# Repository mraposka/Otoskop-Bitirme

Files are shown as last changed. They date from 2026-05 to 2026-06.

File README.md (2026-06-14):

# Otoskop — Motorlu Akıllı Teleskop / Gökyüzü İşaretleyici

Otoskop; bir gök cismini (gezegen, yıldız, takımyıldız vb.) seçtiğinde, kendi
konumunu ve yönelimini ölçüp teleskopu **otomatik olarak** o hedefin azimut/
yükseklik (altitude) açısına döndüren, üzerindeki kamera ile canlı görüntü
veren bir bitirme projesidir.

Sistem üç parçadan oluşur:

1. **Arduino Mega 2560** — "kas + duyu": IMU/pusula, GPS ve iki servo motoru
   sürer. Hedefe yumuşak şekilde nişan alır.
2. **ESP32-CAM (AI-Thinker)** — "ağ geçidi + göz": Wi-Fi, HTTP API, kamera
   (anlık kare + canlı MJPEG yayını) ve Mega ile köprü görevi görür.
3. **Android uygulaması** — kullanıcı arayüzü: hedef seçimi, manuel oynatma,
   kalibrasyon, canlı kamera, telemetri gösterimi.

```
   ┌──────────────┐   Wi-Fi/HTTP   ┌──────────────┐   UART (JSON)  ┌──────────────┐
   │ Android App  │ ─────────────► │  ESP32-CAM   │ ─────────────► │ Arduino Mega │
   │ (hedef/UI)   │ ◄───────────── │ (ağ + kamera)│ ◄───────────── │ (sensör+motor)│
   └──────────────┘   status/JPEG  └──────────────┘   telemetri    └──────────────┘
                                                                         │
                                                            ┌────────────┼────────────┐
                                                         MPU9250        GPS        2x Servo
                                                       (IMU+pusula)  (NEO-6M)    (azimut/alt)
```

---

## İçindekiler

- [Depo yapısı](#depo-yapısı)
- [Nasıl çalışır?](#nasıl-çalışır)
- [Donanım ve kablolama](#donanım-ve-kablolama)
- [Yazılım kurulumu (Arduino IDE)](#yazılım-kurulumu-arduino-ide)
- [Mega firmware yükleme](#mega-firmware-yükleme)
- [ESP32-CAM firmware yükleme](#esp32-cam-firmware-yükleme)
- [Wi-Fi ve cihaz bulma](#wi-fi-ve-cihaz-bulma)
- [HTTP API](#http-api)
- [UART köprüsü ve JSON protokolü](#uart-köprüsü-ve-json-protokolü)
- [Kablosuz kod yükleme (OTA)](#kablosuz-kod-yükleme-ota)
- [Sorun giderme](#sorun-giderme)

---

## Depo yapısı

```
Otoskop/
├── ESP32_Arduino_Firmware/
│   └── mega_otoskop/
│       └── mega_otoskop.ino        # Arduino Mega 2560 firmware (sensör + motor)
├── ESP32_Pure_Firmware/
│   ├── esp32cam_otoskop/
│   │   └── esp32cam_otoskop.ino    # ESP32-CAM firmware (Wi-Fi + kamera + köprü)
│   └── ota/
│       ├── firmware.bin            # Bulut OTA için yayınlanan derlenmiş binary
│       └── version.json            # OTA sürüm bilgisi {"version", "url"}
├── ota_release/
│   └── release.ps1                 # OTA yayın yardımcısı (PowerShell)
├── ServoTest.ino                   # Servo açı testi için bağımsız yardımcı sketch
└── README.md
```

> Not: `firmware.bin` bilerek repoda tutulur (`.gitignore` onu istisna tutar),
> çünkü cihazlar OTA güncellemesini doğrudan GitHub raw URL'sinden indirir.

---

## Nasıl çalışır?

1. **Konum & yönelim ölçümü (Mega):**
   - GPS'ten enlem/boylam (lat/lon) alınır.
   - MPU9250 ile **azimut** (tilt-kompanze manyetometre + gyro complementary
     filter ile gerçek pusula yönü) ve **yükseklik açısı** (ivmeölçer pitch)
     hesaplanır.
2. **Hedef belirleme (App → ESP → Mega):**
   - Uygulama bir hedefin azimut/altitude değerini gönderir.
   - Mega, hedefi servo açısına haritalar ve motorları yumuşakça (slew) döndürür.
   - Hedefe yeterince yaklaşınca **kilit (lock)** durumu raporlanır.
3. **Geri bildirim (Mega → ESP → App):**
   - Mega ~10 Hz telemetri (anlık açı, hedef açı, servo açıları, GPS, IMU/track/
     lock durumları) yollar.
   - ESP bunu önbelleğe alır ve `/status` ile uygulamaya servis eder.
4. **Görüntü (ESP):**
   - Kamera tek kare (`/camera`) veya canlı MJPEG yayını (`/stream`, ayrı port)
     olarak verilir.

---

## Donanım ve kablolama

### Bileşenler

| Parça | Açıklama |
|---|---|
| Arduino Mega 2560 | Ana kontrolcü (sensör + motor) |
| ESP32-CAM (AI-Thinker) | Wi-Fi + kamera + köprü |
| MPU9250 | 9 eksenli IMU (ivme + gyro + AK8963 manyetometre) |
| GPS modülü | NEO-6M / M8N (TinyGPSPlus uyumlu) |
| 2x Servo | Azimut (pan) + Altitude (tilt) ekseni |
| USB–TTL adaptör | ESP32-CAM ilk programlaması için (kartta USB yoksa) |
| Gerilim bölücü | Mega 5V TX → ESP 3.3V RX hattı için |

### Mega bağlantıları

| Bağlantı | Pinler |
|---|---|
| MPU9250 | VCC 3.3V, GND, SDA → 20, SCL → 21 |
| GPS | VCC 5V, GND, GPS-TX → Mega RX2 (17), GPS-RX → Mega TX2 (16) |
| Servo Azimut | Sinyal → pin **9** (harici 5V besleme, ortak GND) |
| Servo Altitude | Sinyal → pin **10** |
| ESP link (TX) | Mega TX1 (18) → **gerilim bölücü 5V→3.3V** → ESP RX2 (GPIO13) |
| ESP link (RX) | Mega RX1 (19) ← ESP TX2 (GPIO15) (3.3V doğrudan) |

### ESP32-CAM bağlantıları

| Bağlantı | Pin |
|---|-----|
| Mega'dan veri girişi (RX2) | GPIO13 (Mega TX1 → gerilim bölücü üzerinden) |
| Mega'ya veri çıkışı (TX2) | GPIO15 (→ Mega RX1) |
| Flash LED (OTA göstergesi) | GPIO4 |

> ⚠️ **Kritik:** Her iki kartın **GND'si ortak** olmalıdır. Mega'nın 5V TX'i
> doğrudan ESP'ye bağlanmamalı; **gerilim bölücü** ile 3.3V'a düşürülmelidir.
> ESP'yi programlarken Mega bağlantısını sökün (UART karışmasın).

---

## Yazılım kurulumu (Arduino IDE)

### 1) ESP32 kart desteği

1. Arduino IDE → **File → Preferences → Additional boards manager URLs**
2. Şu adresi ekleyin:
   `https://espressif.github.io/arduino-esp32/package_esp32_index.json`
3. **Tools → Board → Boards Manager** → **esp32** (Espressif) yükleyin.

### 2) Kütüphaneler

**Sketch → Include Library → Manage Libraries** üzerinden kurun:

| Kütüphane | Yazar / Sürüm | Kullanan |
|---|---|---|
| **ArduinoJson** | Benoît Blanchon (6.x/7.x) | Mega + ESP |
| **TinyGPSPlus** | Mikal Hart | Mega |
| **Servo** | Arduino (built-in) | Mega |
| **ESP32Servo** | (alternatif, gerekirse) | — |

`WiFi`, `WebServer`, `Wire`, `esp_camera`, `ArduinoOTA`, `HTTPClient`,
`HTTPUpdate`, `ESPmDNS` ESP32 çekirdeğiyle birlikte gelir.

---

## Mega firmware yükleme

1. **File → Open** ile `ESP32_Arduino_Firmware/mega_otoskop/mega_otoskop.ino`
   dosyasını açın.
2. **Tools → Board → Arduino Mega or Mega 2560** seçin, doğru COM portunu seçin.
3. **Upload**.
4. Serial Monitor'ü **115200** baud'da açın.

`DEBUG_USB` sabiti `1` iken Mega, hem komutları (`[CMD] ...`), hem 10 Hz
telemetriyi (`{"az":...}`), hem de bir "kalp atışı" satırını (`[LOOP] n=... imuOk=...`)
USB seri monitöre yazar. Bu, sensör/bağlantı doğrulaması için çok kullanışlıdır.

### Mega'da ayarlanabilir parametreler

| Sabit | Açıklama |
|---|---|
| `AZ_RANGE_MIN_DEG` / `AZ_RANGE_MAX_DEG` | Azimut servosunun kapsadığı açı aralığı (varsayılan 0–180°) |
| `ALT_RANGE_MIN_DEG` / `ALT_RANGE_MAX_DEG` | Altitude servo aralığı (0–90°) |
| `SERVO_SLEW_DEG_PER_LOOP` | Servo yumuşatma hızı |
| `LOCK_TOLERANCE_DEG` | Hedef kilidi toleransı |
| `MAG_DECLINATION_DEG` | Yerel manyetik sapma (İstanbul ≈ +6°) |
| `magOffX/Y/Z` | Manyetometre hard-iron offset (kalibrasyonla bulunur) |

---

## ESP32-CAM firmware yükleme

1. **File → Open** ile
   `ESP32_Pure_Firmware/esp32cam_otoskop/esp32cam_otoskop.ino` açın.
2. **Tools** ayarları:

| Ayar | Değer |
|---|---|
| Board | **AI Thinker ESP32-CAM** |
| Upload Speed | 115200 veya 921600 |
| Flash Frequency | 80MHz |
| Partition Scheme | **Minimal SPIFFS (1.9MB APP with OTA)** (OTA için şart) |
| PSRAM | **Enabled** |

3. Kartta USB yoksa **USB–TTL** adaptör kullanın (GPIO0 ↔ GND ile boot moduna alıp
   reset). Doğru COM portunu seçip **Upload** edin.
4. Serial Monitor: **115200** baud.

İlk yükleme bir kez kabloyla yapılmalıdır; sonrasında OTA ile kablosuz
güncellenebilir.

---

## Wi-Fi ve cihaz bulma

ESP, **AP + STA** modunda aynı anda çalışır:

- **AP (erişim noktası):** SSID `Otoskop`, şifre `otoskop123`, IP genelde
  **192.168.4.1**. Android uygulaması doğrudan buna bağlanabilir.
- **STA (istemci):** `WIFI_NETS` listesindeki ağlardan (telefon hotspot'u / ev
  Wi-Fi'si) hangisi varsa ona bağlanır (`WiFiMulti`). Bu, internet erişimi ve
  bulut OTA için gerekir.
- **mDNS:** Cihaz kendini `otoskop.local` olarak yayınlar. Uygulama IP yerine bu
  adı kullanarak cihazı DHCP IP değişse bile otomatik bulabilir.

Ayarlar `esp32cam_otoskop.ino` dosyasında:

```cpp
const char* AP_SSID = "Otoskop";
const char* AP_PASS = "otoskop123";
WifiCred WIFI_NETS[] = {
  { "Nothing", "123456789a" },   // kendi ağ(lar)ını ekle
};
```

---

## HTTP API

API port **80**'de, MJPEG yayını ise tıkanmayı önlemek için ayrı bir port
**81**'de servis edilir.

| Metot | Endpoint | Açıklama |
|---|---|---|
| GET | `/status` | Telemetri JSON (uygulama bunu sürekli sorgular) |
| GET | `/camera` | Tek JPEG kare (snapshot) |
| GET | `/stream` | Canlı MJPEG yayını (**port 81**) |
| GET | `/gps` | `{"lat":.., "lon":.., "fix":bool}` |
| POST | `/target` | `{"name":.., "azimuth":.., "altitude":..}` |
| POST | `/move` | `{"direction":"left\|right\|up\|down", "step":"small\|medium\|large"}` |
| POST | `/correction` | `{"azimuthCorrection":.., "altitudeCorrection":..}` |
| POST | `/calibrate` | Gyro + manyetometre kalibrasyonunu tetikler |
| GET | `/ota/check` | Bulut OTA'yı hemen kontrol eder (yeni sürüm varsa günceller) |

Tüm yanıtlar CORS (`Access-Control-Allow-Origin: *`) başlığı taşır.

### `/status` yanıt alanları

```json
{
  "azimuth": 134.8, "altitude": 42.1,
  "targetAzimuth": 135.4, "targetAltitude": 42.8,
  "servoAz": 67.4, "servoAlt": 42.1,
  "gpsFix": true, "imuOk": true,
  "tracking": true, "targetLocked": false,
  "megaRaw": "...", "megaAgeMs": 80, "megaLines": 1234, "megaBytes": 56789
}
```

`megaRaw / megaAgeMs / megaLines / megaBytes` alanları Mega↔ESP UART bağlantısının
teşhisi içindir (uygulamadaki konsolda görünür). `megaBytes = 0` → fiziksel hat
yok (GND/gerilim bölücü/kablo); `megaAgeMs = -1` → Mega'dan hiç veri gelmedi.

---

## UART köprüsü ve JSON protokolü

ESP ile Mega, 115200 8N1 baud'da satır-sonlu (`\n`) JSON ile konuşur.

**ESP → Mega (komutlar):**

```json
{"cmd":"target","az":135.4,"alt":42.8}
{"cmd":"move","dir":"right","step":"medium"}
{"cmd":"correction","daz":-0.8,"dalt":0.5}
{"cmd":"track","on":true}
{"cmd":"calibrate"}
```

**Mega → ESP (telemetri, ~10 Hz):**

```json
{"az":134.8,"alt":42.1,"taz":135.4,"talt":42.8,"sAz":67.4,"sAlt":42.1,
 "roll":1.2,"pitch":42.1,"yaw":134.8,
 "gps":true,"lat":41.0,"lon":28.9,"imu":true,"trk":true,"lock":false}
```

---

## Kablosuz kod yükleme (OTA)

ESP firmware'i ilk kabloyla yüklendikten sonra **iki yolla** kablosuz
güncellenebilir:

### 1) Aynı ağda — ArduinoOTA

Bilgisayar ESP ile aynı ağdayken Arduino IDE → **Tools → Port** içinde
`otoskop at <IP>` belirir. Normal şekilde **Upload** yapılır.
OTA şifresi: `otoskop123`.

### 2) İnternet üzerinden — Bulut OTA (HTTP pull)

Masaüstü ile ESP farklı ağlardayken kullanılır. ESP belirli aralıklarla
(varsayılan **5 dk**) `version.json` dosyasını kontrol eder:

```json
{ "version": 12, "url": "https://.../firmware.bin" }
```

`version > FW_VERSION` ise `firmware.bin` indirilip cihaz kendini günceller
(indirme sırasında flash LED yanıp söner). `GET /ota/check` ile güncelleme
beklemeden tetiklenebilir.

### Yeni sürüm yayınlama

1. `esp32cam_otoskop.ino` içindeki `#define FW_VERSION` değerini artırın.
2. Arduino IDE → **Sketch → Export Compiled Binary**.
3. Proje kökünde PowerShell ile yardımcı betiği çalıştırın:

```powershell
./ota_release/release.ps1
```

Betik, derlenen `.bin`'i `ESP32_Pure_Firmware/ota/firmware.bin`'e kopyalar ve
`version.json`'daki sürümü `.ino`'daki `FW_VERSION` ile eşitler (BOM'suz UTF-8).
Ardından bu iki dosyayı GitHub'a yükleyin. ESP en geç 5 dk içinde kendini
günceller.

> ⚠️ Betik güvenlik kontrolü yapar: `.ino` dosyası `.bin`'den yeniyse uyarır —
> aksi halde cihaz sonsuz OTA döngüsüne girebilir. `FW_VERSION`'ı değiştirdikten
> sonra **mutlaka yeniden derleyin**.

---

## Sorun giderme

| Belirti | Olası neden / çözüm |
|---|---|
| Uygulamada "ESP32 bağlantısı sağlanamadı" | Telefon `Otoskop` AP'sine bağlı mı? IP `192.168.4.1` mi? mDNS için `otoskop.local` deneyin |
| `megaBytes = 0` | UART fiziksel hattı yok: ortak GND yok, gerilim bölücü yanlış, Mega TX1 (pin 18) / ESP RX2 (GPIO13) bağlantısı hatalı |
| `megaBytes` artıyor ama `megaLines = 0` | Sinyal var ama bozuk — her iki taraf da 115200 8N1 olmalı |
| `imuOk = false` (sürekli kırmızı) | MPU9250 I2C bağlantısı; kod 100 kHz'de çalışır ve saniyede bir yeniden init dener. Kabloları/SDA-SCL'yi kontrol edin |
| Kamera init hatası (`0x105`) | Besleme yetersiz/brownout; kod brownout dedektörünü kapatır, PWDN toggle + 20/10 MHz XCLK dener. Yeterli akım veren USB/güç kullanın |
| Pusula sapması | `calibrate` çalıştırın; `MAG_DECLINATION_DEG`'i kendi konumunuza göre ayarlayın |
| Stream açıkken API donuyor | Yeni firmware'de yayın ayrı portta (81); stream döngüsü içinde API pompalanır. Eski firmware'i güncelleyin |
| Bulut OTA sonsuz döngü | `FW_VERSION` artırıldı ama yeniden derlenmedi; `release.ps1` bu durumda uyarır |
| OTA: **Could Not Activate The Firmware** | İndirme tamam ama doğrulama/aktivasyon başarısız. **En sık neden:** cihaz veya `firmware.bin` **farklı Partition Scheme** ile derlenmiş (ör. cihazda *Huge APP No OTA*, OTA bin *Minimal SPIFFS*). **Çözüm:** Arduino IDE → AI Thinker ESP32-CAM → **Minimal SPIFFS (1.9MB APP with OTA)** + PSRAM Enabled ile **USB'den bir kez** yükle; GitHub'a koyacağın `.bin`'i de **aynı ayarlarla** Export Compiled Binary ile üret |

---

## Lisans / Notlar

Bu, eğitim amaçlı bir bitirme projesidir. Wi-Fi şifreleri, OTA şifresi ve
TLS ayarları (sertifika doğrulaması kapalı) hobi kullanımı içindir; üretim
ortamı için sertleştirilmelidir.

Tanıtım: [Video](https://www.youtube.com/watch?v=3B4UuJV4B6s)

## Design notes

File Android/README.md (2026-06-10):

# Otoskop — ESP32 Tabanlı Otonom Teleskop Mobil Uygulaması

Android Studio projesi (Kotlin, AGP 9.0.0). MVVM + Navigation + Retrofit/OkHttp +
Coroutines mimarisinde modüler yazılmıştır.

## Mimari

```
app/src/main/java/com/kou/otoskop/
├── OtoskopApp.kt                    # Application + servis locator
├── MainActivity.kt                  # Navigation host + runtime izin
├── core/
│   ├── AppConfig.kt                 # IP, port, timeout, polling sabitleri
│   ├── AppError.kt                  # Hata türleri (UI mesajına map'lenir)
│   ├── Resource.kt                  # Success / Failure sealed class
│   └── AstroMath.kt                 # azimuth wrap-around, yön etiketleri
├── data/
│   ├── model/                       # JSON DTO'ları (Moshi)
│   │   ├── TelescopeStatus.kt
│   │   ├── CelestialObject.kt
│   │   ├── VerifyResult.kt
│   │   ├── SkyArea.kt
│   │   └── PhoneSensorData.kt
│   ├── network/                     # Retrofit API'ları + factory
│   │   ├── Esp32Api.kt
│   │   ├── BackendApi.kt
│   │   ├── NetworkFactory.kt
│   │   └── EndpointRewriteInterceptor.kt
│   └── repository/
│       ├── Esp32Repository.kt       # status/move/target/correction/calibrate
│       ├── BackendRepository.kt     # observable-objects + verify-image
│       └── SensorRepository.kt      # FusedLocation + rotation vector
└── ui/
    ├── shared/                      # 4 ViewModel (paylaşılan)
    │   ├── ConnectionViewModel.kt
    │   ├── SensorViewModel.kt
    │   ├── TelescopeViewModel.kt
    │   └── ObjectsViewModel.kt
    ├── widget/                      # Custom view'lar
    │   ├── CompassView.kt           # döner kompas (Canvas)
    │   ├── MjpegView.kt             # MJPEG byte-stream parser
    │   ├── StatusChipView.kt
    │   └── AppErrorView.kt
    ├── connection/ConnectionFragment.kt
    ├── livecamera/LiveCameraFragment.kt
    ├── skyarea/SkyAreaFragment.kt
    ├── objectlist/
    │   ├── ObjectListFragment.kt
    │   └── CelestialObjectAdapter.kt
    └── control/TelescopeControlFragment.kt
```

### Tasarım kararları

- **Servis Locator**: `OtoskopApp` üzerinden tek `Esp32Repository`,
  `BackendRepository`, `SensorRepository` instance'ı; Hilt/Koin yerine
  manuel DI bu boyut için yeterli ve test edilebilir.
- **Endpoint rewrite interceptor**: kullanıcı bağlantı ekranında IP
  değiştirdiğinde Retrofit'i yeniden inşa etmiyoruz — OkHttp interceptor
  her isteğin host/port'unu rewrite ediyor.
- **`Resource<T>`**: `try/catch` her yerde dağılmasın diye Repository'ler
  `Resource.Success` veya `Resource.Failure(AppError)` döner.
- **Native MJPEG parser**: 3. parti widget yok; `MjpegView` JPEG SOI/EOI
  marker'larına göre frame çıkarır.
- **`activityViewModels()`**: 5 fragment arasında `TelescopeViewModel`,
  `ObjectsViewModel`, `SensorViewModel`, `ConnectionViewModel` paylaşılır.

## Gradle / Bağımlılıklar

Tek dokunuş gereksinimi (Android Studio "Sync Now"): değişiklikler
`gradle/libs.versions.toml`, `build.gradle.kts`, `app/build.gradle.kts`'da.

Eklenenler:

- Kotlin 2.0.21 plugin
- Coroutines (`org.jetbrains.kotlinx:kotlinx-coroutines-android`)
- Lifecycle / Fragment / Activity / Navigation (`androidx.navigation:*`)
- RecyclerView
- Retrofit + Moshi converter, OkHttp + logging-interceptor
- Play Services Location (FusedLocation)
- MockWebServer + coroutines-test (test bağımlılıkları)

## Gömülü taraf (Arduino Mega + ESP32-CAM)

Firmware proje kökündeki **[`../firmware/`](../firmware/README.md)** klasöründedir:

- **`firmware/mega_otoskop/`** (Arduino Mega 2560): MPU9250 (tilt-kompanze pusula +
  ivmeden yükseklik), GPS (TinyGPSPlus), 2 servo, complementary filter.
- **`firmware/esp32cam_otoskop/`** (AI-Thinker ESP32-CAM): Wi-Fi AP, HTTP API
  (`/status`, `/target`, `/move`, `/correction`, `/calibrate`, `/camera`, `/stream`,
  `/gps`), kamera ve Mega ile **UART JSON köprüsü**.

Akış: `Android ──WiFi/HTTP──► ESP32-CAM ──UART(JSON)──► Arduino Mega`. App yalnız
ESP ile konuşur; ESP, Mega'nın telemetrisini `/status` olarak servis eder. Kablolama
ve haberleşme protokolü için `firmware/README.md`.

## Gök cismi listesi + AI doğrulama (backend'siz)

Bu sürümde ayrı bir backend sunucu **yoktur**; app üçüncü-parti servisleri doğrudan kullanır:

- **Gözlemlenebilir objeler** → [Visible Planets API](https://api.visibleplanets.dev)
  (ücretsiz, anahtar gerekmez). Gezegenler + Ay + Güneş; az/alt penceresine göre
  cihazda filtrelenir.
- **Görüntü doğrulama** → Google **Gemini** (`gemini-2.5-flash-lite`), app'ten direkt
  multimodal çağrı. Anahtar **Bağlantı ekranında** girilir (cihazda saklanır).
- İlgili kod: `data/network/AstroApi.kt`, `data/network/GeminiApi.kt`,
  `data/repository/DirectBackendRepository.kt`.

## Çalıştırma

1. Android Studio'da projeyi aç → Gradle Sync.
2. Telefonu USB ile bağla veya emülatör başlat.
3. Run.
4. İlk açılışta konum izni ister; sensörler ve GPS otomatik başlar.

## Testler

```bash
gradlew test
```

Test dosyaları:

- `core/AstroMathTest.kt` — azimuth wrap-around mantığı.
- `data/Esp32RepositoryTest.kt` — MockWebServer ile status / target / move.
- `data/BackendRepositoryTest.kt` — observable-objects query parametreleri
  ve `verify-image` cevap akışları (success + correction + not-verified).

## Hata yönetimi

`AppErrorKind` enum'undan UI'a banner:

| Kind | Mesaj |
|---|---|
| `ESP32_UNREACHABLE` | ESP32 bağlı değil |
| `CAMERA_STREAM_FAILED`  | Kamera stream alınamıyor |
| `GPS_UNAVAILABLE` | GPS konumu yok |
| `COMPASS_UNCALIBRATED`  | Telefon pusulası kalibre değil |
| `BACKEND_UNREACHABLE` | Backend API cevap vermiyor |
| `TARGET_NOT_VERIFIED` | Hedef doğrulanamadı |
| `PERMISSION_DENIED` | Gerekli izinler verilmedi |

---

## Uçtan Uca Akış & Örnek İstekler

### 1) ESP32 status polling

`TelescopeViewModel.startPolling()` 750ms'de bir:

```http
GET /status HTTP/1.1
Host: 192.168.4.1
```

Cevap:

```json
{
  "azimuth": 134.8, "altitude": 42.1,
  "targetAzimuth": 135.4, "targetAltitude": 42.8,
  "servoAz": 67.4, "servoAlt": 42.1,
  "gpsFix": true, "imuOk": true,
  "tracking": true, "targetLocked": false
}
```

### 2) Sky Area seçimi → backend obje listesi

```http
GET /observable-objects?latitude=41.0151&longitude=28.9795
    &datetime=2026-05-14T20:30:00Z
    &azimuthMin=120.0&azimuthMax=150.0
    &altitudeMin=30.0&altitudeMax=60.0 HTTP/1.1
Host: backend.example.com
```

Cevap:

```json
[
  { "name": "Mars", "type": "planet", "azimuth": 135.4, "altitude": 42.8,
    "magnitude": -1.2, "visible": true },
  { "name": "Arcturus", "type": "star", "azimuth": 128.0, "altitude": 51.2,
    "magnitude": 0.0, "visible": true }
]
```

### 3) Kullanıcı Mars'ı seçer → ESP32'ye target gönder

```http
POST /target HTTP/1.1
Host: 192.168.4.1
Content-Type: application/json

{ "name": "Mars", "azimuth": 135.4, "altitude": 42.8 }
```

### 4) Snapshot al → backend'e gönder (multipart)

```http
POST /verify-image HTTP/1.1
Host: backend.example.com
Content-Type: multipart/form-data; boundary=...

targetName=Mars
latitude=41.0151
longitude=28.9795
azimuth=134.8
altitude=42.1
image=<JPEG bytes>
```

Düzeltme gerekirse:

```json
{
  "verified": false, "targetName": "Mars",
  "azimuthCorrection": -0.8, "altitudeCorrection": 0.5,
  "message": "Move slightly left and up"
}
```

Doğrulandıysa:

```json
{
  "verified": true, "targetName": "Mars",
  "azimuthCorrection": 0, "altitudeCorrection": 0,
  "message": "Target verified"
}
```

### 5) App otomatik düzeltme gönderir

```http
POST /correction HTTP/1.1
Host: 192.168.4.1
Content-Type: application/json

{ "azimuthCorrection": -0.8, "altitudeCorrection": 0.5 }
```

### 6) Manuel hareket (kullanıcı "sağ + orta")

```http
POST /move HTTP/1.1
Host: 192.168.4.1
Content-Type: application/json

{ "direction": "right", "step": "medium" }
```

`direction`: `left | right | up | down`
`step`: `small | medium | large`

### 7) Kalibrasyon

```http
POST /calibrate HTTP/1.1
Host: 192.168.4.1
```

### 8) MJPEG canlı stream

`MjpegView`, ESP32'nin `multipart/x-mixed-replace` cevabını okur ve her
JPEG frame'ini ImageView'e bağlar:

```http
GET /stream HTTP/1.1
Host: 192.168.4.1
```

---

## Notlar

- `AndroidManifest.xml` `usesCleartextTraffic="true"` + ESP32 IP'leri
  `res/xml/network_security_config.xml`'de whitelist'tir.
- `OtoskopApp.sensorRepo` Activity yaşam döngüsünde start/stop edilir.
- `TelescopeViewModel`'in polling job'ı Fragment `onStart/onStop`'ta
  start/stop edilir; pil tüketimini kontrol altında tutar.
- ESP32 IP'si runtime'da değişebilir: `EndpointRewriteInterceptor` Retrofit
  base URL'i yerine her isteği rewrite eder.

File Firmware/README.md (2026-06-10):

# Otoskop — Arduino IDE ile yükleme

Sketch klasörü: **`OtoskopTelescope/`** (içinde `OtoskopTelescope.ino` + `board_config.h`).

## 1) ESP32 kart desteği

1. Arduino IDE → **File → Preferences → Additional boards manager URLs**
2. Şu adresi ekle (zaten varsa virgülle ayır):

   `https://espressif.github.io/arduino-esp32/package_esp32_index.json`

3. **Tools → Board → Boards Manager** → **esp32** arat → **esp32** (Espressif) yükle.

## 2) Kütüphaneler

**Sketch → Include Library → Manage Libraries** veya Library Manager’dan kur:

| Kütüphane | Arama |
|---|---|
| **ArduinoJson** | Benoît Blanchon, sürüm 7.x |
| **TinyGPSPlus** | Mikal Hart |
| **ESP32Servo** | Kevin Harrington / Madhephaestus |

WiFi, WebServer, Wire, esp_camera ESP32 çekirdeğiyle gelir.

## 3) Kart ayarları (ESP32-CAM AI-Thinker)

**File → Open** ile `OtoskopTelescope/OtoskopTelescope.ino` dosyasını aç (klasör adı ile .ino adı aynı olmalı).

**Tools** menüsü örnek ayarlar:

| Ayar | Değer |
|---|---|
| Board | **AI Thinker ESP32-CAM** |
| Upload Speed | 115200 veya 921600 |
| Flash frequency | 80MHz |
| Partition Scheme | **Huge APP (3MB No OTA/1MB SPIFFS)** veya kamera için önerilen şema |
| PSRAM | **Enabled** |

Kartında USB yoksa **USB–TTL** ile programlama (GPIO0 ↔ GND ile boot modu vb.) gerekir.

## 4) Yükleme

1. Doğru **COM port** seç (Tools → Port).
2. **Sketch → Upload**.

Serial Monitor: **115200** baud.

## 5) Wi-Fi

Varsayılan AP: `Otoskop-ESP` / `telescope123` — IP genelde **192.168.4.1**.

SSID/şifreyi `OtoskopTelescope.ino` dosyasındaki `WIFI_AP_SSID` / `WIFI_AP_PASSWORD` sabitlerinden değiştir.

## PlatformIO ile aynı kod

Arduino sürümü `esp32_firmware/src/main.cpp` ile aynı mantıkta tutulmalı; güncelleme yaparken iki yeri senkronize et veya tek kaynak olarak birini seç.

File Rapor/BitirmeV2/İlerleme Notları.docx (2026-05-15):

Yapay Zekâ Destekli Otomatik Teleskop Yönlendirme, Gök Cismi Tanıma ve Gök Cismi Veri Seti Oluşturma Platformu

İlerleme Raporu

Öğrenci: Abdulkadir Can Kinsiz
Proje Danışmanı: Dr. Öğr. Üyesi Önder Yakut
Bölüm: Bilişim Sistemleri Mühendisliği

1. Giriş

Bu rapor, dönem başında belirlenen çalışma planına göre bitirme projesinde gelinen mevcut durumu, elde edilen sonuçları, yapılan geliştirmeleri ve halen tamamlanması gereken adımları açıklamak amacıyla hazırlanmıştır. Projenin genel amacı; düşük maliyetli elektronik bileşenler, mobil uygulama, ESP32 tabanlı kontrol altyapısı, kamera görüntüsü, sensör verileri ve ilerleyen aşamada yapay zekâ destekli doğrulama yapısını bir araya getirerek otomatik teleskop yönlendirme ve gök cismi tanıma sistemi geliştirmektir.

Dönem başında hazırlanan mevcut durum raporunda; literatür araştırması, sistem mimarisi hazırlığı, mekanik prototipleme denemeleri, teleskop kolimasyonu/optik iyileştirme çalışmaları ve yazılım tarafında ilk otonom yönlendirme denemeleri yapılmıştı. Ayrıca ikinci dönem için mekanik tasarımın tamamlanması, iki eksende kararlı hareket üretimi, GPS/IMU verileriyle başlangıç referansı oluşturulması, hedef seçimi, motor komutu üretimi, mobil uygulama geliştirme ve sunucu tarafı haberleşme mimarisi hedeflenmişti.

Bu dönem içerisinde proje, yalnızca teorik tasarım aşamasında kalmamış; mobil uygulama arayüzü, ESP32 bağlantı yapısı, demo çalışma modu, hedef listeleme, alan belirleme, manuel kontrol, kamera akışı için hazırlanan ekran yapısı ve 3D baskı mekanik prototipleriyle daha somut bir sistem prototipine dönüştürülmüştür. Çalışma hâlen nihai ürün seviyesinde değildir; ancak yazılım ve donanım entegrasyonunun temel yapısı büyük ölçüde oluşturulmuştur.

2. Dönem Başındaki Planın Özeti

Dönem başında belirlenen ana hedefler şu şekildeydi:

Planlanan Çalışma | Dönem Başındaki Durum | Bu Dönemdeki Hedef
Literatür ve sistem mimarisi | Temel araştırma ve bileşen seçimi yapılmıştı | Mimariyi uygulamaya taşımak
Mekanik tasarım | İlk tasarım ve montaj denemeleri yapılmıştı | 3D baskı parçalarla prototip oluşturmak
Optik hizalama | Kolimasyon ve odak iyileştirmeleri yapılmıştı | Kamera entegrasyonuna uygun hale getirmek
Otonom yönlendirme | Sensör verisi ve motor komutu mantığı denenmişti | Hedefe yönelme ve düzeltme altyapısı kurmak
Mobil uygulama | Plan aşamasındaydı | Kontrol, hedef seçimi ve kamera ekranlarını geliştirmek
ESP32 kontrol sistemi | Deneysel aşamadaydı | HTTP tabanlı kontrol altyapısı hazırlamak
Sunucu tarafı | Plan aşamasındaydı | Daha sonraki aşamaya temel oluşturmak
Yapay zekâ doğrulama | Kavramsal aşamadaydı | Snapshot/doğrulama akışını hazırlamak

Bu plan doğrultusunda bu dönem ağırlıklı olarak mobil uygulama, ESP32 haberleşmesi, demo prototip, 3D baskı mekanik geliştirme ve kullanıcı kontrol akışı üzerine çalışılmıştır.

3. Bu Dönem Yapılan Çalışmalar

3.1. Mobil Uygulama Geliştirme Çalışmaları

Bu dönem içerisinde projenin kullanıcı ile etkileşime geçtiği ana katman olan Android mobil uygulama üzerinde önemli ilerleme sağlanmıştır. Mobil uygulama, teleskop sistemini yalnızca uzaktan kontrol eden basit bir kumanda olarak değil; bağlantı yönetimi, hedef seçimi, gözlem alanı belirleme, manuel kontrol, telemetri takibi ve kamera görüntüleme gibi işlevleri bir araya getiren merkezi bir kontrol arayüzü olarak tasarlanmıştır.

Mobil uygulamada şu temel ekranlar ve işlevler geliştirilmiştir:

- ESP32 bağlantı ve demo modu ekranı,
- GPS ve IMU durum bilgisini gösteren telemetri ekranı,
- mevcut azimut/yükseklik ve hedef azimut/yükseklik gösterimi,
- manuel yönlendirme butonları,
- küçük/orta/büyük hareket adımı seçimi,
- kalibrasyon butonu,
- tracking açma/kapatma kontrolü,
- gözlemlenebilir alan belirleme ekranı,
- gök cismi listeleme ve hedef seçme ekranı,
- canlı kamera akışı için hazırlanan ekran,
- snapshot alma ve doğrulama butonu.

Bu yapı sayesinde kullanıcı, ileride gerçek teleskop sistemine bağlandığında hedef seçebilecek, teleskopun yönelimini izleyebilecek, manuel müdahale yapabilecek ve kamera görüntüsü üzerinden doğrulama sürecini başlatabilecektir.

3.2. Demo Modu ve Gerçek Cihaz Bağlantı Yapısı

Geliştirme sürecinde sistemin her zaman gerçek ESP32 donanımı bağlıyken test edilmesi pratik değildir. Bu nedenle mobil uygulamada demo modu oluşturulmuştur. Demo modu sayesinde ESP32 bağlı değilken de sahte telemetri verileri, örnek hedef listesi ve kamera placeholder ekranı üzerinden uygulama akışı test edilebilmektedir.

Bu yaklaşım, yazılım geliştirme sürecinde önemli bir avantaj sağlamıştır. Çünkü uygulamanın ekran geçişleri, hedef seçimi, alan belirleme, tracking durumu, snapshot doğrulama butonu ve kullanıcı arayüzü gerçek donanım beklenmeden denenebilmiştir.

Gerçek cihaz bağlantısı için ise ESP32’nin IP adresi üzerinden bağlantı kurulacak bir yapı hazırlanmıştır. Kullanıcı bağlantı ekranında ESP32 IP adresini girerek bağlantı testi yapabilmektedir. Bu yapı özellikle saha kullanımı için önemlidir; çünkü teleskop sistemi internet bağlantısı olmayan ortamlarda da kendi yerel ağı üzerinden mobil uygulama ile haberleşebilecektir.

3.3. ESP32 Tabanlı Kontrol Yazılımı

Bu dönem ESP32 tarafında da kontrol yazılımı için temel altyapı oluşturulmuştur. ESP32, sistemde düşük seviye kontrol birimi olarak düşünülmüştür. Mobil uygulamadan gelen hareket, hedef seçimi, kalibrasyon, kamera ve durum sorgulama komutlarının ESP32 tarafından alınması hedeflenmiştir.

ESP32 tarafında planlanan temel işlevler şunlardır:

İşlev | Açıklama
Durum sorgulama | GPS, IMU, hedef, servo/motor ve tracking durumlarını döndürme
Manuel hareket | Sağ, sol, yukarı, aşağı hareket komutlarını işleme
Hedef alma | Mobil uygulamadan seçilen hedefin açı bilgilerini alma
Kalibrasyon | Başlangıç referansı veya mevcut yönelimi sıfırlama
Kamera akışı | ESP32-CAM üzerinden MJPEG görüntü sağlama
Snapshot | Anlık görüntü alıp doğrulama sürecine hazırlama
Düzeltme komutu | Yapay zekâ veya kullanıcı geri bildirimiyle küçük hareket düzeltmeleri yapma

Bu aşamada sistemin temel amacı, mobil uygulama ile ESP32 arasında standart ve genişletilebilir bir iletişim kanalı oluşturmaktır. Böylece ileride yapay zekâ doğrulama, gerçek kamera akışı ve hassas motor kontrolü eklendiğinde mevcut yapı üzerine kolayca entegre edilebilecektir.

3.4. Telemetri, GPS ve IMU Takibi

Mobil uygulamada GPS ve IMU durumlarını gösteren bir telemetri ekranı hazırlanmıştır. Bu ekranda sistemin mevcut azimut/yükseklik değerleri, hedef azimut/yükseklik değerleri ve servo açıları görüntülenmektedir.

Bu ekranın temel amacı, teleskopun mevcut yönelimi ile hedef yönelimi arasındaki farkı kullanıcıya anlaşılır şekilde sunmaktır. Böylece sistemin hedefe ne kadar yaklaştığı, kalibrasyonun doğru çalışıp çalışmadığı ve manuel komutların açı değerlerine etkisi takip edilebilmektedir.

Dönem başında GPS ve IMU verilerinin başlangıç referansı oluşturmak, hedef ile mevcut yönelim farkını hesaplamak ve motorlara komut üretmek amacıyla kullanılacağı planlanmıştı. Bu dönem bu plan mobil uygulama arayüzü ve ESP32 kontrol mantığı içinde somutlaştırılmıştır.

3.5. Manuel Kontrol ve Kalibrasyon Arayüzü

Otonom sistemlerde manuel kontrol, geliştirme ve test sürecinde kritik öneme sahiptir. Bu nedenle mobil uygulamada yukarı, aşağı, sağ ve sol yönlendirme butonları oluşturulmuştur. Ayrıca hareket adımları küçük, orta ve büyük olarak üç seviyeye ayrılmıştır.

Bu yapı sayesinde kullanıcı:

- teleskopu elle yönlendirebilir,
- hareket yönlerinin doğru çalışıp çalışmadığını test edebilir,
- motor/servo tepkilerini gözlemleyebilir,
- hedefe yaklaşırken büyük adım kullanabilir,
- ince ayar yaparken küçük adım kullanabilir,
- sistemin başlangıç referansını kalibre edebilir,
- tracking modunu açıp kapatabilir.

Bu arayüz, sistem tam otonom hale gelmeden önce donanımın güvenli şekilde test edilmesine imkân tanımaktadır. Ayrıca ileride yapay zekâdan gelen mikro düzeltme komutlarının manuel kontrol mantığıyla aynı hareket altyapısını kullanması planlanmaktadır.

3.6. Gözlemlenebilir Alan Belirleme

Bu dönem geliştirilen önemli özelliklerden biri de kullanıcının gözlem yapılacak gökyüzü alanını belirleyebilmesidir. Mobil uygulamada pusula benzeri bir arayüz üzerinden kullanıcının yön seçmesi ve pencere yarıçapını ayarlaması sağlanmıştır.

Bu yapı ile kullanıcı, örneğin yalnızca kuzeydoğu yönündeki belirli bir azimut ve yükseklik aralığını gözlem alanı olarak seçebilir. Uygulama bu alanı sayısal açı aralığına dönüştürerek sistemin yalnızca o bölgede bulunan gök cisimlerini listelemesine imkân tanır.

Bu özellik gerçek saha koşulları için önemlidir. Çünkü her gözlem ortamında gökyüzünün tamamı açık değildir. Binalar, ağaçlar, balkon sınırları, dağlar veya ışık kaynakları bazı yönleri kapatabilir. Kullanıcı tarafından belirlenen gözlem penceresi sayesinde sistem, fiziksel olarak görülemeyen hedefleri liste dışı bırakabilecek şekilde tasarlanmıştır.

3.7. Gök Cismi Listeleme ve Hedef Seçimi

Alan belirleme ekranından sonra mobil uygulamada seçilen gökyüzü aralığında gözlemlenebilir gök cisimlerinin listelenmesi için bir ekran hazırlanmıştır. Bu ekranda Mars, Jüpiter, Arcturus gibi örnek hedefler; tür, parlaklık, azimut ve yükseklik bilgileriyle birlikte gösterilmektedir.

Bu ekran, projenin kullanıcı deneyimi açısından önemli bir parçasıdır. Geleneksel teleskop kullanımında kullanıcı gök cismini kendisi bulmak, yıldız haritasından konumunu anlamak ve teleskopu manuel olarak o noktaya çevirmek zorundadır. Bu projede ise kullanıcı yalnızca gözlem alanını belirledikten sonra sistemin sunduğu hedef listesinden seçim yapabilecektir.

Bu dönem için hedef listeleme ekranı demo veriler üzerinden hazırlanmıştır. İlerleyen aşamada bu yapının gerçek astronomik konum hesapları ve efemeris verileriyle desteklenmesi planlanmaktadır.

3.8. Kamera Akışı ve Snapshot Doğrulama Hazırlığı

Projenin önemli hedeflerinden biri, teleskoptan alınan kamera görüntüsünün mobil uygulama üzerinde izlenebilmesi ve anlık görüntüler üzerinden hedef doğrulama yapılabilmesidir. Bu dönem mobil uygulamada kamera ekranı hazırlanmış ve demo modda gerçek kamera akışı olmadığını belirten bir placeholder yapısı oluşturulmuştur.

ESP32-CAM bağlandığında bu ekranda MJPEG kamera akışının gösterilmesi hedeflenmektedir. Ayrıca “Snapshot & doğrula” butonu ile kameradan anlık görüntü alınması ve bu görüntünün ileride yapay zekâ destekli doğrulama sürecine gönderilmesi planlanmıştır.

Mevcut durumda bu yapı arayüz ve sistem akışı düzeyinde hazırlanmıştır. Yapay zekâ modelinin gerçek görüntü üzerinden hedef tanıması ve motorlara mikro düzeltme üretmesi sonraki geliştirme aşamasında tamamlanacaktır.

3.9. 3D Baskı Gövde ve Mekanik Prototipleme

Bu dönem yazılım geliştirmelerine paralel olarak mekanik prototip üzerinde de çalışılmıştır. 3D baskı ile üretilecek gövde, bağlantı parçaları, elektronik kutu ve teleskop montaj elemanları için tasarım denemeleri yapılmıştır.

Dönem başındaki planda mekanik tasarımın bitirilmesi, motorların konumlandırılması, gövde rijitliği, titreşim azaltma ve kablo yönetimi gibi konuların tamamlanması hedeflenmişti. Bu dönem bu hedef doğrultusunda mekanik tasarım daha somut hale getirilmiş, 3D model parçaları hazırlanmış ve prototip montajı için uygun parça yapısı oluşturulmuştur.

3D baskı parçaların kullanılması, geliştirme sürecinde hızlı revizyon avantajı sağlamıştır. Ölçü hataları, bağlantı noktaları, kablo çıkışları, elektronik kart yerleşimi ve kamera konumu gibi unsurlar hızlı şekilde test edilebilmiştir.

3.10. Prototip Montajı ve Fiziksel Doğrulama

Bu dönem oluşturulan prototip yalnızca yazılım ekranlarından ibaret değildir. ESP32, kamera, sensörler, bağlantı kabloları ve mekanik parçaların bir arada kullanılabileceği fiziksel bir prototip yapısı da hazırlanmıştır.

Fiziksel prototipte dikkat edilen temel noktalar şunlardır:

- elektronik bileşenlerin teleskop hareketini engellememesi,
- kabloların hareketli parçalara takılmaması,
- kamera modülünün uygun açıyla yerleştirilmesi,
- gövdenin fazla ağırlık oluşturmaması,
- bakım ve hata ayıklama için kartlara erişimin korunması,
- ileride motor entegrasyonuna uygun bağlantı noktalarının bırakılması.

Bu çalışmalar sonucunda sistemin yazılım, donanım ve mekanik taraflarının birlikte çalışabileceği bir geliştirme platformu ortaya çıkarılmıştır. Prototip henüz nihai ürün seviyesinde değildir; ancak sonraki testler için kullanılabilecek fiziksel altyapı oluşmuştur.

4. Dönem Başındaki Plana Göre İlerleme Durumu

Planlanan Adım | Mevcut İlerleme | Durum
Literatür ve sistem mimarisi | %90 | Büyük ölçüde tamamlandı
Donanım bileşenlerinin belirlenmesi | %85 | ESP32, kamera, GPS/IMU ve mekanik yapı netleşti
Kolimasyon ve optik iyileştirme | %80 | Temel ayarlar yapıldı, saha testleri devam etmeli
Mekanik tasarım | %65 | 3D model ve prototip oluşturuldu, nihai montaj tamamlanmadı
ESP32 kontrol yazılımı | %60 | API/komut yapısı hazırlandı, gerçek donanım testleri sürmeli
Mobil uygulama | %75 | Ana ekranlar, demo mod, hedef seçimi ve kontrol akışı hazırlandı
Manuel kontrol | %70 | Arayüz hazır, motor hassasiyeti test edilmeli
Alan belirleme | %70 | Demo arayüz çalışıyor, gerçek sensör verisiyle test edilmeli
Gök cismi listeleme | %60 | Demo listeleme hazır, gerçek astronomik veri entegrasyonu eksik
Kamera akışı | %45 | Arayüz hazır, ESP32-CAM canlı akışı gerçek sistemde test edilmeli
Snapshot doğrulama | %40 | Buton ve akış hazır, AI modeli henüz tam entegre edilmedi
Yapay zekâ tanıma | %25 | Kavramsal ve altyapı seviyesi, model entegrasyonu kaldı
Sunucu tarafı | %20 | Planlandı, ancak öncelik mobil/ESP32 prototipe verildi
Veri seti üretimi | %25 | Meta veri yaklaşımı belirlendi, gerçek veri toplama süreci başlamalı

Genel olarak dönem başında planlanan çalışmaların önemli bir kısmında ilerleme sağlanmıştır. Özellikle mobil uygulama ve prototip kontrol akışı, başlangıç planına göre en somut ilerleme kaydedilen alanlar olmuştur. Buna karşılık yapay zekâ model entegrasyonu, gerçek kamera akışı, hassas motor kontrolü ve sunucu tarafı veri yönetimi hâlen geliştirilmesi gereken başlıklar olarak kalmıştır.

5. Elde Edilen Sonuçlar

Bu dönem sonunda aşağıdaki sonuçlara ulaşılmıştır:

1. Mobil uygulama prototipi oluşturulmuştur. Kullanıcı artık demo mod üzerinden bağlantı ekranını, kontrol ekranını, alan belirleme ekranını, hedef listeleme ekranını ve kamera/snapshot ekranını test edebilmektedir.
2. ESP32 ile haberleşmeye uygun kontrol mimarisi hazırlanmıştır. ESP32’nin sistemde düşük seviye kontrol birimi olarak çalışması ve mobil uygulamadan gelen komutları işlemesi için gerekli temel yapı planlanmış ve uygulanmaya başlanmıştır.
3. Demo modu sayesinde donanım olmadan test yapılabilir hale gelinmiştir. Bu durum geliştirme sürecini hızlandırmış, arayüz ve kullanıcı akışlarının gerçek donanım beklenmeden doğrulanmasını sağlamıştır.
4. Gözlemlenebilir alan belirleme yaklaşımı geliştirilmiştir. Kullanıcının belirli bir azimut/yükseklik aralığını seçebilmesi, sistemin ileride fiziksel engelleri ve gerçek gözlem koşullarını dikkate alabilmesi için önemli bir temel oluşturmuştur.
5. Hedef listeleme ve seçim akışı hazırlanmıştır. Mars, Jüpiter, Arcturus gibi örnek cisimler üzerinden hedef seçimi akışı test edilmiştir.
6. Manuel kontrol ve kalibrasyon arayüzü geliştirilmiştir. Kullanıcının teleskopu sağ/sol/yukarı/aşağı yönlendirebilmesi, hareket adımı seçebilmesi ve tracking durumunu kontrol edebilmesi sağlanmıştır.
7. Kamera ve snapshot doğrulama ekranı hazırlanmıştır. Gerçek kamera akışı henüz tam entegre edilmemiş olsa da, MJPEG görüntüleme ve snapshot doğrulama sürecine uygun arayüz oluşturulmuştur.
8. 3D baskı mekanik prototip çalışmaları ilerletilmiştir. Gövde, bağlantı parçaları ve montaj yapısı üzerinde prototipleme yapılmış; fiziksel sistemin kurulabilirliği test edilmeye başlanmıştır.

6. Karşılaşılan Teknik Zorluklar

Bu dönem yapılan çalışmalarda bazı teknik zorluklar gözlemlenmiştir. Bunlar projenin çok bileşenli yapısından kaynaklanmaktadır. Sistem yalnızca bir mobil uygulama veya yalnızca bir elektronik devre değildir; mobil uygulama, ESP32, kamera, GPS, IMU, motor sistemi, mekanik gövde ve ileride eklenecek yapay zekâ doğrulama modülü birlikte çalışmak zorundadır.

Başlıca zorluklar şunlardır:

Zorluk | Açıklama | Çözüm / Yaklaşım
ESP32 bağlantı kararlılığı | Saha ortamında Wi-Fi bağlantısı kopabilir | Bağlantı testi ve demo moda dönüş yapısı hazırlandı
Sensör doğruluğu | GPS/IMU verileri drift veya gecikme gösterebilir | Kalibrasyon ve filtreleme ihtiyacı belirlendi
Motor hassasiyeti | Küçük açısal hareketlerde mekanik boşluk etkili olabilir | Küçük/orta/büyük hareket adımları eklendi
Kamera performansı | ESP32-CAM düşük ışıkta sınırlı olabilir | İlk aşamada parlak hedeflere odaklanma planlandı
Yapay zekâ entegrasyonu | Gerçek zamanlı doğrulama henüz tamamlanmadı | Snapshot akışı hazırlandı, model entegrasyonu sonraya bırakıldı
Mekanik stabilite | 3D baskı parçalar nihai dayanıklılığı sağlamayabilir | Prototip üzerinde revizyon yapılması planlandı

7. Kalan Çalışmalar

Projenin tamamlanması için aşağıdaki çalışmaların yapılması gerekmektedir:

1. ESP32-CAM canlı kamera akışının gerçek teleskop üzerinde test edilmesi Kamera akışı mobil uygulamada gerçek zamanlı olarak gösterilmeli, gecikme ve görüntü kalitesi ölçülmelidir.
2. Motor/servo hareketlerinin hassaslaştırılması İki eksende daha kararlı hareket için mekanik boşluklar, hareket adımları ve açı dönüşümleri test edilmelidir.
3. GPS ve IMU kalibrasyonunun güçlendirilmesi Sensör verileri daha güvenilir hale getirilmeli, drift ve manyetik bozulma etkileri azaltılmalıdır.
4. Yapay zekâ tabanlı görüntü doğrulama modelinin sisteme eklenmesi Snapshot görüntüsü üzerinden hedef cismin doğrulanması ve merkezden sapma değerinin hesaplanması sağlanmalıdır.
5. Mikro düzeltme döngüsünün tamamlanması Yapay zekâ veya görüntü işleme sonucu elde edilen sapma değerleri ESP32’ye gönderilmeli ve teleskop küçük hareketlerle hedefi merkezde tutmalıdır.
6. Sunucu tarafı ve veri seti altyapısının geliştirilmesi Görüntü, tarih, konum, hedef adı, azimut, yükseklik ve doğrulama sonucu gibi meta veriler düzenli biçimde saklanmalıdır.
7. Gerçek gökyüzü testlerinin yapılması Ay, Jüpiter, Mars, Venüs ve parlak yıldızlar gibi hedefler üzerinde gerçek saha testleri yapılmalıdır.
8. Mekanik gövdenin nihai hale getirilmesi 3D baskı prototip daha sağlam, dengeli ve saha kullanımına uygun hale getirilmelidir.

8. Genel Değerlendirme

- Bu dönem yapılan çalışmalar sonucunda proje, dönem başındaki teorik ve deneysel hazırlık aşamasından daha somut bir prototip seviyesine taşınmıştır. Başlangıçta literatür araştırması, sistem mimarisi, mekanik denemeler, kolimasyon ve ilk yönlendirme mantığı üzerinde yoğunlaşılmışken; bu dönem mobil uygulama, ESP32 kontrol altyapısı, demo mod, alan belirleme, hedef listeleme, manuel kontrol, kamera/snapshot ekranı ve 3D baskı mekanik prototip üzerine ilerleme sağlanmıştır.
- Gelinen noktada sistem tamamen bitmiş bir otonom teleskop ürünü değildir. Ancak projenin temel çalışma döngüsü büyük ölçüde ortaya çıkarılmıştır. Kullanıcı mobil uygulama üzerinden bağlantı kurabilecek, gözlem alanı belirleyebilecek, hedef seçebilecek, teleskopu manuel olarak yönlendirebilecek ve kamera doğrulama sürecini başlatabilecek bir arayüze sahip hale gelmiştir.
- Bundan sonraki aşamada en kritik çalışmalar; gerçek kamera akışının teleskop üzerinde test edilmesi, motor hareketlerinin hassaslaştırılması, GPS/IMU kalibrasyonunun iyileştirilmesi, yapay zekâ destekli hedef doğrulama modelinin entegre edilmesi ve gerçek gökyüzü testlerinin yapılmasıdır. Bu adımlar tamamlandığında sistem, düşük maliyetli, taşınabilir ve geliştirilebilir bir otonom gözlem platformu haline gelecektir.

## 9. Ekler

9. Ek-1: Android Mobil Uygulama Projesi GitHub bağlantısı: https://github.com/mraposka/Otoskop-Android
10. Ek-2: ESP32 Kontrol Yazılımı Projesi GitHub bağlantısı: https://github.com/mraposka/Otoskop
11. Ek-3: Mobil Uygulama Demo Videosu Video bağlantısı: https://youtube.com/shorts/V_GBohDTpk4
12. Ek-4: Mekanik Prototip / 3D Baskı Videosu Video bağlantısı: https://youtube.com/shorts/rHJjfhN5mRE

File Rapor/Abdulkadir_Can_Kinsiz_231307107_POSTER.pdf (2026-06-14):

# KOCAELİ ÜNİVERSİTESİ

## Teknoloji Fakültesi Bilişim Sistemleri Mühendisliği Anabilim Dalı

Yapay Zekâ Destekli Otomatik Teleskop Yönlendirme, Gök Cismi Tanıma ve Gök Cismi Veri Seti Oluşturma Platformu

## Abdulkadir Can KİNSİZ | Danışman: Dr. Öğr. Üyesi Önder YAKUT

## Özet

Bu projede gök ve uzay cisimlerinin düşük maliyetli donanımlarla gözlemlenmesi, izlenmesi ve görüntülerinin canlı paylaşılması için otomatik bir teleskop sistemi geliştirilmiştir. İdeal tasarımda Raspberry Pi 5, yüksek çözünürlüklü kamera ve bulut tabanlı yapay zekâ destekli cisim tespiti hedeflenmiş; bütçe ve donanım kısıtları nedeniyle Arduino Mega 2560, ESP32-CAM, PHP/MySQL web platformu ve Android mobil uygulamadan oluşan bir prototip kurulmuştur.

## Giriş

Astronomi | gözlemleri | geleneksel | olarak | pahalı | ve | karmaşık | ekipman
gerektirdiğinden amatör kullanıcılar ve eğitim kurumları için erişilebilirliği sınırlıdır. Raspberry Pi ve Arduino gibi düşük maliyetli platformların yaygınlaşması, gözlem ve görüntü paylaşımının ucuz biçimde otomatikleştirilmesini mümkün kılmıştır. Bu çalışmanın amacı, teleskobu otomatik yönlendiren, kamera görüntüsünü gerçek zamanlı yayınlayan ve gözlem verilerini web ile mobil arayüzler üzerinden sunan entegre bir sistem ortaya koymaktır.

## Metot

Sistem; mekanik düzenek, gömülü yazılım, web platformu ve mobil uygulama olmak üzere dört katmanda tasarlanmıştır. Arduino Mega 2560; MPU9250 IMU ve NEO-6M GPS verilerini tümleyici filtre ile birleştirerek konum/yönelim kestirimi yapar ve servo motorları sürer. ESP32-CAM HTTP API ve MJPEG yayın sağlar; Kotlin Android uygulaması mDNS keşfi, efemeris hesaplaması ve MJPEG akış çözümlemesi ile saha kullanımını destekler.

## Deneysel Çalışma

Prototipin üretim ve test sürecinde mekanik ve elektriksel sorunlarla karşılaşılmıştır. Kasnak-kayış aktarımı torku kaldıramamış, PLA parçalar kırılmış; fiberglas parçalar kullanılmıştır. Güç dalgalanmaları iki ESP modülü ve bir IMX477 kamerayı arızalandırmıştır. Saha testlerinde canlı görüntü akışı, telemetri, hedefleme ile web/mobil arayüzler değerlendirilmiş; Ay ve Mars gözlemleri elde edilmiştir.

## Sonuçlar

Testler, düşük maliyetli prototipin temel hedeflerini karşıladığını göstermiştir: teleskop servolarla yönlendirilebilmiş, ESP32-CAM üzerinden canlı görüntü sağlanmış ve IMU/GPS tümlemesiyle anlamlı konum-yönelim bilgisi elde edilmiştir. Web platformu ve Android uygulaması saha kullanımı açısından işlevsel bulunmuştur; prototip kavramın uygulanabilirliğini doğrulamakta ve genişletilmeye uygun bir temel sunmaktadır.

## Prototip Sistemi ve Uygulama Görselleri

Kurulu prototip sistemi (bütün hali) | Hedef seçimi | Gökyüzü alanı | Canlı kamera
Ay gözlemi | Mars gözlemi
GitHub: github.com/mraposka/Otoskop-Bitirme | Demo: youtube.com/watch?v=3B4UuJV4B6s

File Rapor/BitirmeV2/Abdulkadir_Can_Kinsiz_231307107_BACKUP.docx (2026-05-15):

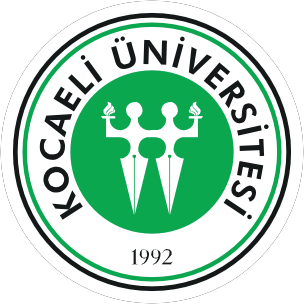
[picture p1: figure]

KOCAELİ ÜNİVERSİTESİ

Fen Bilimleri Enstitüsü

BİLİŞİM SİSTEMLERİ MÜHENDİSLİĞİ ANABİLİM DALI

Yapay Zekâ Destekli Otomatik Teleskop Yönlendirme, Gök Cismi Tanıma ve Gök Cismi Veri Seti Oluşturma Platformu

ABDULKADİR CAN KİNSİZ

Dr. Öğr. Üyesi Önder Yakut

LİSANS TEZİ

~~Kocaeli,~~ ~~202~~~~5~~

Onay Sayfası

Etik Beyan ve Araştırma Fonu Desteği

Kocaeli Üniversitesi Fen Bilimleri Enstitüsü tez yazım kurallarına uygun olarak

hazırladığım bu tez/proje çalışmasında,

- Bu tezin/projenin bana ait, özgün bir çalışma olduğunu,

- Çalışmamın hazırlık, veri toplama, analiz ve bilgilerin sunumu olmak üzere tüm

aşamalarında bilimsel etik ilke ve kurallara uygun davrandığımı,

- Bu çalışma kapsamında elde edilen tüm veri ve bilgiler için kaynak gösterdiğimi

ve bu kaynaklara kaynakçada yer verdiğimi,

- Bu çalışmanın Kocaeli Üniversitesi’nin abone olduğu intihal yazılım programı

kullanılarak Fen Bilimleri Enstitüsü'nün belirlemiş olduğu ölçütlere uygun

olduğunu,

- Kullanılan verilerde herhangi bir tahrifat yapmadığımı,

- Tezin/Projenin herhangi bir bölümünü bu üniversite veya başka bir üniversitede

başka bir tez/proje çalışması olarak sunmadığımı,

beyan ederim.

☒ Bu tez/proje çalışmasının herhangi bir aşaması hiçbir kurum/kuruluş tarafından maddi/alt yapı desteği ile desteklenmemiştir.

☐ Bu tez/proje çalışması kapsamında üretilen veri ve bilgiler ............................................ tarafından ......................................... no’lu proje kapsamında maddi/alt yapı desteği alınarak gerçekleştirilmiştir.


Herhangi bir zamanda, çalışmamla ilgili yaptığım bu beyana aykırı bir durumun saptanması durumunda, ortaya çıkacak tüm ahlaki ve hukuki sonuçları kabul ettiğimi bildiririm.

...........................
(İmza)

Abdulkadir Can Kinsiz
(Öğrencinin Adı Soyadı)

Yayımlama ve Fikri Mülkiyet Hakları

Fen Bilimleri Enstitüsü tarafından onaylanan lisansüstü tezimin/projemin tamamını veya herhangi bir kısmını, basılı ve elektronik formatta arşivleme ve aşağıda belirtilen koşullarla kullanıma açma izninin Kocaeli Üniversitesi’ne verdiğimi beyan ederim. Bu izinle Üniversiteye verilen kullanım hakları dışındaki tüm fikri mülkiyet haklarım bende kalacak, tezimin/projemin tamamının ya da bir bölümünün gelecekteki çalışmalarda (makale, kitap, lisans ve patent vb.) kullanımı bana ait olacaktır. Tezin/projenin kendi özgün çalışmam olduğunu, başkalarının haklarını ihlal etmediğimi ve tezimin/projenin tek yetkili sahibi olduğumu beyan ve taahhüt ederim. Tezimde yer alan telif hakkı bulunan ve sahiplerinden yazılı izin alınarak kullanılması zorunlu metinlerin yazılı izin alarak kullandığımı ve istenildiğinde suretlerini Üniversiteye teslim etmeyi taahhüt ederim.

Yükseköğretim kurulu tarafından yayınlanan “Lisansüstü Tezlerin Elektronik Ortamda Toplanması, Düzenlenmesi ve Erişime Açılmasına İlişkin Yönerge” kapsamında tezim aşağıda belirtilen koşullar haricinde YÖK Ulusal Tez Merkezi/ Kocaeli Üniversitesi Kütüphaneleri Açık Erişim Sisteminde erişime açılır.

☐ Enstitü yönetim kurulu kararı ile tezimin/projemin erişime açılması mezuniyet tarihinden itibaren 2 yıl ertelenmiştir.

☐ Enstitü yönetim kurulu gerekçeli kararı ile tezimin/projemin erişime açılması mezuniyet tarihinden itibaren 6 ay ertelenmiştir.

☒ Tezim/projem ile ilgili gizlilik kararı verilmemiştir.

...........................
(İmza)

Abdulkadir Can Kinsiz
(Öğrencinin Adı Soyadı)

ÖNSÖZ VE TEŞEKKÜR

Bu tez, yapay zekâ destekli gök cismi tanıma, otomatik teleskop yönlendirme ve gözlem verilerinin bulut tabanlı bir veri setine dönüştürülmesi amacıyla geliştirilmiştir. Düşük maliyetli donanım bileşenleri ile modern görüntü işleme yöntemlerinin bir araya getirildiği bu çalışma, Türkiye’de amatör astronomi ve otonom gözlem sistemleri için erişilebilir ve sürdürülebilir bir altyapı sunmayı hedeflemektedir. Tez sürecinde teleskop donanımlarının entegrasyonu, sensörlerden konum–yönelim hesaplamaları, görüntülerin yapay zekâ ile sınıflandırılması ve veri kayıt mekanizmalarının oluşturulması gibi aşamalar sistematik biçimde yürütülmüştür.

Bu araştırmanın hazırlanmasında süreç boyunca motivasyon ve desteklerini esirgemeyen, akademik rehberliği ve yönlendirmeleri için danışmanım Dr. Öğr. Üyesi Önder Yakut’a teşekkür ederim.

Kasım – 2025 Abdulkadir Can Kinsiz

ŞEKİLLER DİZİNİ

Yapay Zekâ Destekli Otomatik Teleskop Yönlendirme, Gök Cismi Tanıma ve Gök Cismi Veri Seti Oluşturma Platformu

Özet

Bu tez, düşük maliyetli elektronik bileşenler, yapay zekâ tabanlı görüntü işleme teknikleri ve otonom kontrol mekanizmalarını bir araya getirerek tamamen kendi kendine çalışabilen yenilikçi bir teleskop gözlem sistemi geliştirmeyi amaçlamaktadır. Sistem; konum, yönelim, görüntü ve sensör verilerini eşzamanlı olarak değerlendirerek gökyüzünü otomatik tarayabilmekte, teleskopu hedef cisimlere yönlendirebilmekte ve tanımlanan nesneleri yapay zekâ algoritmalarıyla sınıflandırabilmektedir. Raspberry Pi merkezli kontrol yapısı, motor sürücülerle birlikte çalışarak teleskopun yatay ve dikey eksenlerde yüksek hassasiyetle hareket etmesini sağlar. Teleskoba bağlı kamera tarafından alınan görüntüler gerçek zamanlı olarak analiz edilir ve sistem, hedef cismin doğru konumda olup olmadığını sürekli kontrol eder.

Gözlemler sırasında kaydedilen görüntüler; tarih, konum, nesne tipi, parlaklık ve model güven oranı gibi ayrıntılı meta verilerle birlikte işlenir. Bu veriler hem yerel depolama birimlerinde tutulur hem de internet bağlantısının bulunduğu durumlarda bulut tabanlı bir veri havuzuna aktarılır. Süreç sonunda geniş kapsamlı, açık erişimli ve sürekli büyüyen bir “Gökyüzü Veri Seti” oluşturulacaktır. Bu veri seti, astronomi araştırmalarında kullanılabileceği gibi makine öğrenmesi model eğitimi, uzaktan eğitim uygulamaları, bilim iletişimi çalışmaları ve dijital sanat çalışmaları için de önemli bir kaynak oluşturmaktadır.

Tez, manuel teleskop kullanımından kaynaklanan hataları ortadan kaldırarak daha tutarlı, kesintisiz ve herkes tarafından erişilebilir bir gözlem deneyimi sunmayı hedefler. Açık kaynaklı yapısı sayesinde öğrenciler, amatör astronomlar ve bağımsız araştırmacılar tarafından geliştirilebilir, uyarlanabilir ve uzun vadede sürdürülebilir bir gözlem altyapısı haline gelmesi amaçlanmaktadır.

Anahtar Kelimeler: Otonom Teleskop Sistemi, Yapay Zekâ, Gök Cismi Tanıma, Görüntü İşleme, Astronomik Veri Seti

Artificial Intelligence–Powered Automated Telescope Pointing, Celestial Object Recognition, and Astronomical Object Dataset Generation Platform

Abstract

This thesis aims to develop an innovative, fully autonomous telescope observation system by integrating low-cost electronic components, artificial intelligence–based image processing methods, and automated control mechanisms. The system is designed to operate independently, continuously analyzing the sky, detecting celestial objects, and adjusting the telescope’s orientation without human intervention. Using a Raspberry Pi as the central control unit, the system processes data from sensors, motor drivers, and the camera module to precisely manage the telescope’s horizontal and vertical movements. Real-time image analysis allows the system to verify whether the target object is correctly centered, enabling stable tracking and uninterrupted observation sessions.

Images captured during observations are enriched with detailed metadata such as date, geographic coordinates, object type, brightness level, and AI confidence scores. These data are stored locally and automatically uploaded to a cloud-based repository when an internet connection is available. As the system collects and labels observations over time, it will form a comprehensive and publicly accessible “Sky Object Dataset.” This dataset is intended to support a wide range of applications, including astronomy research, machine learning model training, educational tools, remote learning environments, and digital art thesis.

By eliminating the manual effort and potential errors associated with traditional telescope operations, the thesis aims to provide a more consistent, reliable, and user-friendly observation experience. Its open-source structure enables students, amateur astronomers, researchers, and hobbyists to modify, enhance, or expand the system according to their needs. Ultimately, the thesis seeks to democratize access to astronomical observation, create a sustainable and scalable technological framework, and offer a versatile platform that bridges scientific exploration, education, and creative fields.

Keywords: Autonomous Telescope System, Artificial Intelligence, Celestial Object Recognition, Image Processing, Astronomical Datase

1. GİRİŞ

Astronomik gözlemler, insanlığın evrene dair merakının en temel unsurlarından biri olmuş ve tarih boyunca bilimsel gelişmelerin önünü açmıştır. Geleneksel gözlem yöntemleri, teleskopun tamamen kullanıcı tarafından kontrol edilmesini gerektiren, yüksek dikkat ve deneyim isteyen süreçlere dayanır. Bu yöntemlerde teleskopun hizalanması, gök cisminin kadrajda tutulması, poz süresinin ayarlanması ve verilerin kaydedilmesi gibi birçok aşama manuel olarak yapılır. Bu durum, hem zaman alıcıdır hem de özellikle amatör astronomlar veya öğrenciler için gözlem sürecinin verimliliğini ciddi biçimde düşürmektedir. Ayrıca manuel gözlemler, tekrar edilebilir bilimsel çıktı üretmekte zorluk yaşar; çünkü insan faktöründen kaynaklanan hata payı yüksektir.

Modern teknolojilerin gelişmesi ile yapay zekâ, görüntü işleme ve mikrodenetleyici tabanlı otomasyon sistemleri astronomi alanında devrim niteliğinde yenilikler ortaya çıkarmıştır. Özellikle düşük maliyetli bilgisayar kartları (Raspberry Pi vb.), hassas motor kontrol sistemleri ve derin öğrenme tabanlı görüntü sınıflandırma teknikleri, teleskopların insan müdahalesi olmadan çalışabilmesine olanak sağlamıştır. Böylece “otonom teleskop” kavramı ortaya çıkmış; otomatik yönlendirme, hedef takip ve veri kaydı sistemleri astronomi çalışmalarında önem kazanmaya başlamıştır.

Bu tez bu teknolojik dönüşümü doğrudan kullanarak; gök cisimlerini otomatik olarak tanıyabilen, hedefi kadrajda tutan, görüntüyü işleyip meta veri üreten ve bunları yerel ya da bulut tabanlı veri tabanına kaydedebilen bir otonom teleskop sistemi geliştirmeyi amaçlamaktadır. Tez, düşük maliyetli, taşınabilir, kullanıcı dostu ve açık kaynaklı bir çözüm sunarak astronomiyle ilgilenen herkesin kendi gözlem ve veri üretim altyapısına sahip olmasını hedeflemektedir.

Geliştirilen sistem yalnızca gözlem sürecini otomatik hâle getirmekle kalmamakta, aynı zamanda uzun yıllar boyunca büyüyebilecek nitelikte kapsamlı bir “Gökyüzü Veri Seti” oluşturulmasını da sağlamaktadır. Bu veri seti bilimsel araştırmalarda kullanılabileceği gibi eğitim, dijital sanat, medya üretimi ve makine öğrenmesi çalışmaları için de önemli bir kaynak olacaktır. Ayrıca tez, astronomi meraklılarının kendi çevrelerinden veri toplayarak evrensel bir gözlem ağına katkı sunabilmelerine olanak tanımaktadır.

Bu çalışmanın amacı, yapay zekâ destekli otomatik gök cismi tanıma, teleskop yönlendirme, veri kaydı ve bulut entegrasyonu özelliklerine sahip, düşük maliyetli ve sürdürülebilir bir otonom teleskop sistemi tasarlamak, geliştirmek ve performansını değerlendirmektir.

2. GENEL BİLGİLER

Astronomik gözlem teknolojileri son on yılda önemli bir dönüşüm sürecine girmiştir. Bu dönüşüm, özellikle düşük maliyetli bilgisayar platformlarının, açık kaynak donanımların ve kompakt görüntüleme sistemlerinin yaygınlaşmasıyla hız kazanmıştır. Geleneksel teleskop sistemleri çoğunlukla kullanıcıya bağımlı, manuel kontrol gerektiren ve yüksek maliyetli ekipmanlara dayanmaktaydı. Ancak hem donanım maliyetlerinin düşmesi hem de yapay zekâ temelli görüntü analizi yöntemlerinin gelişmesi, amatör astronomiden araştırma amaçlı gözlem topluluklarına kadar geniş bir kitlenin gökyüzü gözlemlerine katkı sunabileceği yeni bir dönemi başlatmıştır.

Günümüzde astronomik gözlemlerde sıklıkla başvurulan yapay zekâ temelli görüntü işleme yöntemleri, gök cismi tespiti, sınıflandırması ve hareket takibi gibi süreçlerde önemli avantajlar sunmaktadır. Örneğin [1], [2] ve [7] gibi çalışmalarda optik teleskop görüntülerinin otomatik olarak işlenmesi, gök cisimlerinin gerçek zamanlı tespiti ve gözlem akışının operatör müdahalesine gerek kalmadan sürdürülebilmesi gösterilmiştir. Bu çalışmalar, gök cisimlerinin otomatik takibini mümkün kılarak hem insan hatasını azaltmakta hem de uzun süreli gözlem görevlerinde performansı artırmaktadır.

Bununla birlikte literatürde yer alan mevcut sistemlerin büyük bir kısmı ya profesyonel gözlemevlerinde kullanılan yüksek maliyetli donanımlara bağlıdır ya da belirli tekil görevlerle sınırlıdır. Örneğin meteor izleme sistemleri [4], [5] yalnızca meteor olaylarına odaklanırken; yıldız takip sistemleri [6] düşük maliyetli yapılarıyla dikkat çekse de veri paylaşımı, sınıflandırma veya bulut tabanlı arşivleme gibi özellikler sunmamaktadır. Benzer şekilde optik teleskoplarla yapılan uzay nesnesi tespit çalışmalarında [2], [7], [10] daha çok yapay zekâ modellerinin performans analizleri ön plandadır; ancak bu sistemlerin çoğu gerçek zamanlı otonom yönlendirme kabiliyetine sahip değildir.

Bu bağlamda geliştirilen tez, mevcut literatürde gözlemlenen eksikliklere doğrudan karşılık gelen bütünleşik bir yaklaşım sunmaktadır. Düşük maliyetli donanım kullanılarak otonom bir teleskop sistemi kurulması; görüntülerin yapay zekâyla yorumlanması, teleskop yönünün otomatik olarak ayarlanması, gözlem sonucunda elde edilen görüntülerin ve meta verilerin kayıt altına alınması; bunların yerel veya çevrimiçi ortamlarda saklanarak açık bir veri setine dönüştürülmesi; literatürde birlikte ele alınmayan, ancak modern gözlem sistemlerinin ihtiyaç duyduğu bütünlüklü bir yapıdır. Sistem; teleskop, görüntüleme birimi, yapay zekâ modelleri, motor kontrol mekanizması ve veri depolama altyapısını bir araya getiren bütünleşik bir mimariye sahiptir.

Bu yaklaşımın en önemli yeniliklerinden biri, verinin yalnızca analiz edilmek üzere tüketilmesi değil; doğrudan kullanıcı tarafından üretilerek paylaşıma açılmasıdır. Literatürdeki büyük ölçekli veri setlerinin çoğu uluslararası ajanslar tarafından üretilmiş olup genellikle lisans kısıtları taşır veya güncel gözlem koşullarını yansıtmaz. Mevcut veri setlerinin çoğu uzay teleskoplarından, uydulardan veya yüksek çözünürlüklü profesyonel sensörlerden elde edildiği için amatör gözlem koşullarıyla uyumlu değildir. Bu nedenle [6], [9], [13] gibi çalışmalarda düşük maliyetli donanım kullanılarak gözlem yapılmasının önemi vurgulanmış; geniş katılımlı veri üretiminin, özellikle yerde konuşlu küçük açıklıklı teleskoplarla yürütülen gözlem çalışmalarında önemli bir rol oynadığı ifade edilmiştir.

Bu tez kapsamındaki otonom gözlem sistemi, kamera sensörü olarak düşük maliyetli modüllerle uyumlu çalışacak şekilde tasarlanmıştır. Tez için IMX477 gibi yüksek performanslı sensörler önerilse de, maliyet kısıtları nedeniyle ESP32-CAM gibi daha kompakt ve erişilebilir kameralar da sistem mimarisine dâhil edilebilmektedir. Bu durum, literatürde [4], [5] ve [6] kapsamındaki çalışmalarla paraleldir; bu çalışmalar düşük maliyetli görüntüleme cihazlarının bilimsel gözlem için yeterli seviyede veri üretebildiğini göstermektedir.

Otonom teleskop sistemlerinde yalnızca görüntüleme bileşenleri değil, aynı zamanda yönlendirme mekanizması da hayati önem taşır. Sistem; step motorlar, motor sürücü devreleri ve mikrodenetleyici birimleriyle donatılarak teleskopun hedef cisimlere otomatik olarak yönlendirilebilmesini sağlar. Bu yönlendirme süreci sırasında kullanıcının yalnızca gözlem yapılacak gök cismini seçmesi yeterlidir; sistem, mevcut konum bilgisi, zamanı ve sensör verilerini kullanarak önceden belirlenen nesnenin açı farkını hesaplar, motorları doğru şekilde çalıştırır ve teleskopu istenen konuma getirir. Bu tür otomatik yönlendirme mekanizmaları [7], [8] gibi çalışmalarda farklı algoritmalarla gösterilmiş olsa da, düşük maliyetli donanımlarla bütünleşik açık veri üretimi ile sunulan bir sistem literatürde sınırlıdır.

Elde edilen görüntülerin saklanması ve işlenmesi süreci, modern astronomik gözlem mimarilerinin en kritik yapı taşlarından biridir. Sistem; görüntüleri tarih, konum, parlaklık bilgisi, tespit edilen gök cisminin türü ve yapay zekâ modelinin güven oranıyla birlikte kaydederek bunları yerel ve çevrimiçi veri tabanlarına aktarmaktadır. Bu yaklaşım, [14], [15] ve [16] gibi çalışmalarda vurgulanan astronomik veri yönetimi pratikleriyle uyumludur ve geniş ölçekli açık veri setlerinin oluşturulmasına katkı sağlar.

Sonuç olarak bu bölümde ele alınan tarihsel ve teknik çerçeve, geliştirilen sistemin neden gerekli olduğunu açıkça ortaya koymaktadır. Manuel kontrol gerektiren teleskop sistemleri artık modern astronominin taleplerine yanıt verememekte; yapay zekâ, otomasyon ve açık veri kavramlarıyla zenginleşen yeni nesil yapılar, hem bilimsel üretimi hem de topluluk astronomisini destekleyecek düzeye ulaşmıştır.

3. MALZEME VE YÖNETİM

Bu bölümde araştırmada kullanılan donanımlar, yazılım bileşenleri, veri toplama yöntemi, yapay zekâ temelli sınıflandırma süreci, teleskop yönlendirme mekanizması, cihazlar arası iletişim yapısı ve gözlem deneyinin nasıl yürütüldüğü ayrıntılı biçimde açıklanmaktadır. Kullanılan tüm malzemeler, sistemin bir bütün halinde çalışmasını sağlayan temel bileşenler olarak ele alınmış; her bir bileşenin araştırma sürecindeki işlevi, görev kapsamı ve diğer bileşenlerle ilişkisi sistematik bir çerçeve içinde sunulmuştur.

3.1. KULLANILAN DONANIM BİLEŞENLERİ

Araştırmada kullanılan donanımlar, hem teleskop tabanlı gözlem mekanizmasını hem de otonom kontrolü mümkün kılan elektronik bileşenleri içermektedir. Bu donanımlar, optik sistemler, sensörler, mikrodenetleyiciler, motor ve motor sürücü devreleri ile güç bileşenlerinden oluşmaktadır.

3.1.1. TELESKOP SİSTEMİ

Gözlem mekanizmasının temelini oluşturan teleskop, 76 mm açıklığa ve 700 mm odak uzaklığına sahip Newton tipi bir reflektör modelidir. Bu teleskop gök cisimlerinin görüntülenmesi için temel optik sistemi sağlamaktadır. Kullanılan teleskop, küçük açıklığına rağmen gezegen gibi parlak gök cisimlerinin kaydedilmesine uygun olup, geniş amatör topluluklarda bilinen başlangıç seviyesi bir modeldir. Farklı odak uzaklıklarına sahip göz mercekleri (SR4, H6, H12.5, H20 mm ve Plössl marka lensler) gözlem koşullarına göre değiştirilerek hedef cismin büyütme düzeyi ayarlanmıştır. Bu lens seti, özellikle gezegenlerin farklı parlaklık ve konum koşullarına göre gerektiğinde daha geniş veya daha dar görüntü alanı elde edebilmek için kullanılmıştır.

Proje sürecinde teleskop, farklı ortamlara taşınması ve saha kullanımı sırasında maruz kaldığı küçük çarpmalar ve titreşimler nedeniyle optik hizasını (kolimasyon/mercek–odak doğrultusu) kısmen kaybetmiştir. Bu durum; görüntüde netlik azalması, odaklamada güçlük ve özellikle parlak cisimlerin çevresinde dağılma/bozulma şeklinde gözlemlenmiştir. Ayrıca uzun pozlama veya ardışık çekimlerde yıldızların noktasal görünümü bozulmuş, ışık yoğunluğu sensör üzerine homojen dağılmadığı için görüntü kalitesi tutarsız hale gelmiştir. Bu tür hizalama sorunları, hem tespit (gök cismi tanıma) doğruluğunu hem de veri seti üretiminde elde edilen görüntülerin karşılaştırılabilirliğini olumsuz etkileyebilmektedir. Bu nedenle optik bileşenlerin mekanik bağlantıları kontrol edilerek kolimasyon ayarları yeniden yapılmış ve odak doğrultusu iyileştirilmiştir. Aşağıdaki iki görselde, hizalama bozulmasının mercek hizasına etkisi ile gerekli kolimasyon ayarları yapıldıktan sonra elde edilen iyileşme örnek olarak sunulmaktadır.

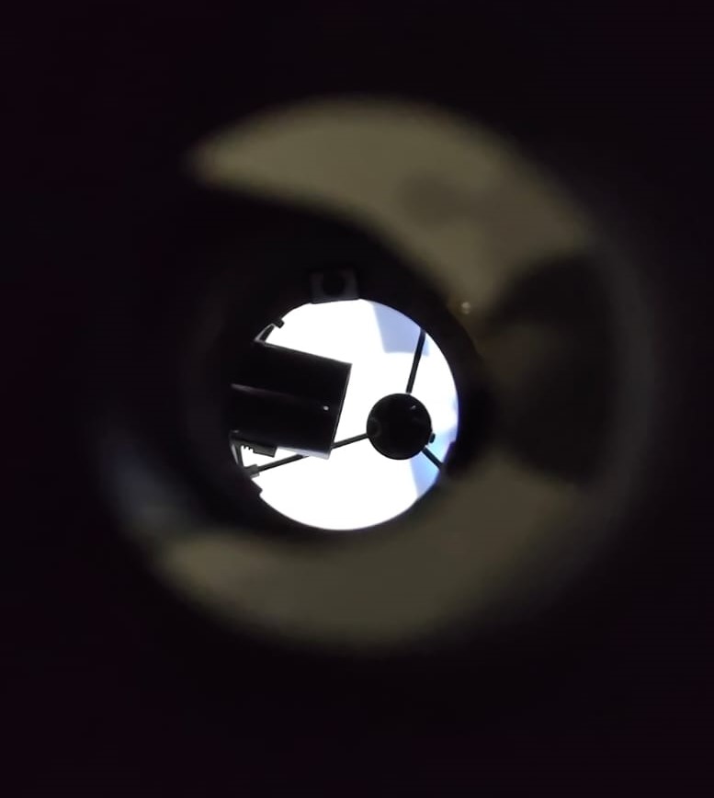
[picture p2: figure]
daire, siyah, hafif içeren bir resim Yapay zeka tarafından oluşturulmuş içerik yanlış olabilir.

Şekil 1. Kolimasyon bozulmasının optik eksene etkisi.

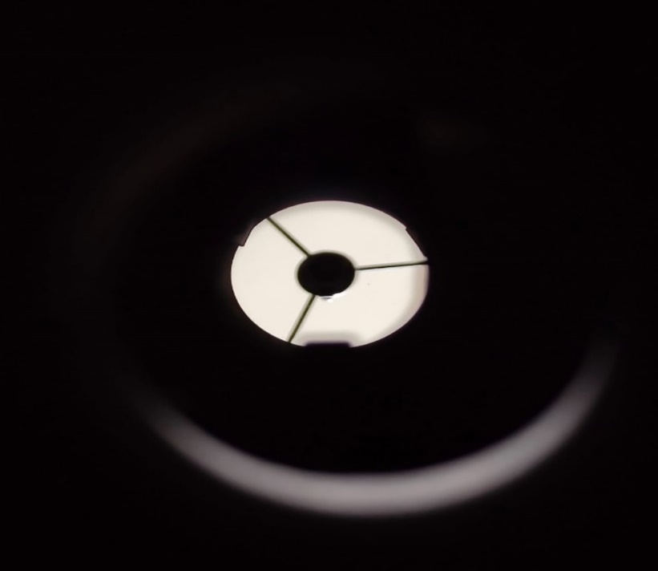
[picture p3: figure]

Şekil 2. Kolimasyon düzeltmesi sonrası elde edilen doğru hizalama.

3.1.1.1. MERCEK AYARI VE OPTİK KOLİMASYON SÜRECİ

Amatör astronomi ve uygulama alanlarında “mercek ayarı” ifadesi çoğu zaman tek bir işlemi değil, teleskobun görüntü kalitesini doğrudan etkileyen iki temel ayar türünü birlikte kapsayan genel bir tanım olarak kullanılır. Bu kapsamın ilk bileşeni kolimasyondur; yani birincil ve ikincil aynaların (ve buna bağlı olarak odaklayıcı ekseninin) ortak bir optik eksen üzerinde doğru şekilde hizalanmasıdır. İkinci bileşen ise odaklamadır; yani oluşan görüntünün odak düzleminin göz merceği ya da kamera sensörü üzerinde en doğru noktaya getirilmesidir. Özellikle Newton tipi yansıtmalı teleskoplarda görüntüyü oluşturan ana eleman bir mercek değil, tüpün arka kısmında yer alan parabolik birincil aynadır. Bu ayna gökyüzünden gelen ışığı belirli bir odak düzleminde toplar; tüp ağzına yakın konumlanan ikincil (diyagonal) ayna ise birincil aynadan gelen ışığı odaklayıcıya yönlendirerek görüntünün oküler veya sensör üzerinde oluşmasını sağlar. Dolayısıyla Newtonian sistemlerde günlük kullanımda “mercek ayarı” denildiğinde pratikte çoğunlukla ayna hizalaması (kolimasyon) ve bunu takip eden fokus optimizasyonu kastedilir.

Kolimasyonun temel hedefi, teleskobun en keskin görüntüyü verdiği optik eksenin gözlemci/sensör ekseniyle çakışmasını sağlamaktır. Kolimasyon doğru değilse odak “yakalanmış gibi” görünse bile, özellikle yüksek büyütmelerde yıldızlar noktasal yapısını kaybeder; gezegen ayrıntıları yumuşar, kontrast düşer ve görüntüde yönlü/asimetrik bozulmalar artar. Bu nedenle kolimasyon, Newtonian teleskoplarda performansı belirleyen en kritik bakım ve kalibrasyon adımlarından biri olarak değerlendirilir. Odaklama ise kolimasyon doğru şekilde tamamlandıktan sonra görüntü keskinliğini maksimize eden son aşamadır; bir anlamda sistemin potansiyelini görünür hale getirir. Bu tez kapsamında “mercek ayarı” konusu yalnızca görsel gözlem kalitesi açısından değil, aynı zamanda görüntü işleme ve yapay zekâ tabanlı tanıma algoritmalarının kararlılığı, veri seti üretiminde standart görüntü kalitesinin korunması ve sistemin otonom çalışmasındaki güvenilirlik açısından da kritik görülmüştür. Bu sebeple mercek ayarı başlığı altında kolimasyon ve odaklamanın yöntemi, uygulanışı, kontrol adımları ve sahada doğrulanması ayrıntılı biçimde ele alınmıştır.

3.1.1.2. NEWTONİAN OPTİK SİSTEMİNİN TEMEL YAPISI VE EKSEN KAVRAMLARI

Newton tipi reflektör teleskoplar temel olarak birincil ayna, ikincil ayna, odaklayıcı ve ikincil aynayı taşıyan spider (örümcek) yapısından oluşur. Birincil ayna, ışığı toplayıp odak düzleminde görüntüyü oluşturan parabolik yüzeydir. İkincil (diyagonal) ayna ise birincil aynadan gelen ışığı yaklaşık 90 derece saptırarak odaklayıcıya taşır ve görüntünün oküler ya da sensöre iletilmesini sağlar. Odaklayıcı, oküler veya kamerayı odak düzlemine göre ileri–geri hareket ettirerek fokus ayarının yapılmasına imkân veren mekanizmadır. Spider yapısı da ikincil aynayı tüp merkezinde konumlandıran ince kollardan oluşur ve sistemin mekanik stabilitesinde rol oynar.

Bu optik düzenekte “hizalama” ifadesi, gerçekte üç ayrı geometrik/optik referansın birbirleriyle doğru ilişkiye getirilmesini amaçlar. Bunlardan ilki odaklayıcı eksenidir; oküler veya kamera doğrultusunu temsil eder. İkincisi birincil aynanın optik eksenidir; parabolik aynanın simetri doğrultusu olup en iyi görüntü bu eksen üzerinde elde edilir. Üçüncüsü ise ikincil aynanın yönlendirme doğrultusudur; birincilden gelen ışığın odaklayıcıya eksenel ve simetrik biçimde taşınmasını sağlayan ayna konumu ve eğimini ifade eder. Kolimasyonun başarısı bu üç bileşenin birlikte doğru hizalanmasına bağlıdır ve Newtonian teleskoplarda genellikle sistematik bir sıra izlenir. Önce ikincil aynanın odaklayıcı altında geometrik konumu düzeltilir; ardından ikincil aynanın eğimi ayarlanarak birincil aynanın merkezi “hedeflenir”; son aşamada ise birincil aynanın hassas eğimi yapılarak optik eksen odaklayıcı ekseniyle çakıştırılır. Bu sıralama, bir adımda yapılan hatanın sonraki adımlarda büyümesini engeller ve tekrarlanabilir, kontrollü bir kolimasyon süreci sağlar.

3.1.1.3. HATALI KOLİMASYONUN GÖRÜNTÜ KALİTESİNE ETKİLERİ

Kolimasyon bozulduğunda ortaya çıkan etkiler hem görsel gözlemde hem de astrofotoğrafik kayıtlarda belirgin hale gelir. Bu etkiler özellikle yüksek büyütmelerde ve hızlı optik sistemlerde (düşük f oranlarında) daha kolay fark edilir, çünkü optik eksendeki küçük kaçıklıklar dahi görüntüye daha güçlü şekilde yansır. Kolimasyon hatasının en tipik sonucu, sistemin en net olması beklenen bölgesinin kaymasıdır; gözlemci hedefi görüş alanının merkezine alsa bile optimum keskinliğe ulaşmak zorlaşır. Yıldız görüntülerinde noktasal yapı yerine asimetri ve kuyruklanma görülebilir; bu bozulma yalnızca odak ayarıyla giderilemeyen “kalıcı bir bulanıklık” hissi oluşturur. Benzer biçimde gezegen gözlemlerinde ince detaylar yumuşar; Jüpiter’in bantları, Satürn’ün halka yapısı veya Ay üzerindeki küçük krater ayrıntılarında kontrast azalır ve beklenen keskinlik kaybolur. Astrofotoğraf tarafında ise alan dengesizliği dikkat çeker: Çerçevenin bir köşesinde yıldızlar farklı yönde bozulurken diğer köşede farklı bir deformasyon görülebilir ve bazı bölgelerde odak iyi görünürken bazı bölgelerde “odak kaçmış” izlenimi oluşur. Bu durum yalnızca görsel kaliteyi düşürmekle kalmaz, görüntü işleme ve yapay zekâ tabanlı analizlerde de kararsızlığa neden olabilir; kenar/özellik çıkarımı zorlaşır, aynı sınıftaki nesnelerin görünümü tutarsızlaşır ve yanlış pozitif/yanlış negatif oranlarında artış gözlenebilir. Bu nedenle kolimasyon, yalnızca “görüntüyü güzelleştirme” amacı taşıyan bir işlem değil, sistemin ölçüm ve algoritma tabanlı çıktı kalitesini doğrudan belirleyen kritik bir kalibrasyon adımı olarak değerlendirilmelidir.

Kolimasyon işlemi optik yüzeylere yakın çalışmayı gerektirdiğinden, hem mekanik güvenlik hem de optik yüzeylerin korunması önem taşır. İşleme başlamadan önce teleskobun devrilmeyecek ve ani hareket etmeyecek şekilde sabitlenmesi gerekir; Dobson taban ya da tripod kullanılıyorsa kilit mekanizmaları kontrol edilmelidir. Kolimasyonun ilk kurulum aşamasında gündüz veya iyi aydınlatılmış bir ortam tercih edilmesi, optik elemanları daha rahat görmeyi sağlar; gece yapılacak uygulamalarda ise göz kamaştırmayan, yumuşak bir ışık kaynağı kullanmak daha uygundur. Aynalar ve kaplamalar hassas olduğundan, parmak izi, çizik veya kimyasal temas görüntü kalitesini kalıcı biçimde düşürebilir; bu yüzden doğrudan ayna yüzeyine temas edilmemeli ve temizlik/koruma konusunda dikkatli olunmalıdır. Kolimasyon aracı kullanılacaksa oküler çıkarılır, odaklayıcı bölgesi temizlenir ve odaklayıcıdaki mekanik gevşeklikler kontrol edilir; çünkü odaklayıcıda boşluk olması hizalama okumasını yanıltabilir. Birincil aynada merkez işaretinin bulunması da kritik bir noktadır; merkez işareti yoksa veya hatalı konumlandırılmışsa kolimasyonun güvenilirliği azalır ve yapılan ayarlar tekrarlanabilir sonuç vermeyebilir. Son olarak ayar vidalarının işlevi anlaşılmadan işleme başlanmamalıdır; birincil ayna kolimasyon vidaları ile varsa kilitleme vidaları (lock) ve ikincil aynanın merkez vidası ile eğim vidaları birbirine karıştırıldığında ayar daha da bozulabilir. Kolimasyonun “hızlıca çevirme” yaklaşımıyla yapılması hatayı büyütebildiği için, her adımın küçük hareketlerle ve arada kontrol edilerek ilerletilmesi doğru yöntemdir.

Kolimasyon farklı hassasiyet seviyelerinde farklı araçlarla gerçekleştirilebilir ve her aracın güçlü olduğu bir kullanım alanı vardır. Bu tez çalışmasında hedef, sahada da uygulanabilir ve tekrarlanabilir bir yöntem sunmak olduğundan araçlar işlevlerine göre değerlendirilmiştir. Basit bir kolimasyon kapağı (pinhole cap) ile odaklayıcı eksenini kabaca referans almak mümkündür; bu yöntem temel hizalama ve hızlı kontrol için pratik bir başlangıç sağlar. İkincil aynanın odaklayıcı altında doğru konumlandırılmasında sight tube (bakış tüpü) gibi araçlar öne çıkar; ikincilin geometrik merkezlemesi ve uygun yerleşimi açısından oldukça etkilidir. Birincil aynanın hassas eğim ayarı için Cheshire, güvenilir bir standart olarak kabul edilir ve “son ayar” aşamasında yüksek doğruluk sağlar. Lazer kolimatör ise hız avantajı nedeniyle sahada zaman kazandırabilir; ancak cihazın kendi doğruluğu, odaklayıcıya tam oturması ve mekanik toleranslar sonucu ciddi şekilde etkileyebildiğinden tek başına nihai doğrulama aracı olarak görülmemelidir. Nihai doğrulamada yıldız testi çok güçlü bir yöntemdir; bununla birlikte atmosfer koşulları ve teleskobun termal dengesi sonuçları etkileyebileceği için uygun şartlarda uygulanmalıdır. Uygulamada en güvenilir yaklaşım, ikincil aynayı sight tube ile doğru konuma getirmek, birincil aynayı Cheshire ile hassas ayarlamak ve ardından yıldız testiyle son doğrulamayı yapmaktır.

Kolimasyon sürecinin ilk aşaması, ikincil aynanın odaklayıcı altında geometrik olarak doğru konumda olduğundan emin olmaktır. Bu aşamada amaç, odaklayıcıdan bakıldığında ikincil aynanın mümkün olduğunca dairesel ve merkezde görünmesini sağlamaktır. Kolimasyon kapağı veya sight tube odaklayıcıya takılarak içeri bakıldığında ikincil ayna çoğu zaman elips formunda görülür ve bu elipsin odaklayıcı açıklığına göre ortalanması hedeflenir. İkincil ayna merkezden kayıksa, örümcek kollarının gerginliği kontrol edilmeli ve kolların eşit gerginlikte olduğundan emin olunmalıdır; çünkü dengesiz gerginlik ikincilin tüp içinde kaymasına neden olabilir. Gerekirse ikincil aynayı taşıyan yapının tüp içindeki ileri–geri konumu çok küçük miktarlarda ayarlanarak merkezleme yapılır. Bazı durumlarda ikincil aynanın aşırı sağ/sol ya da yukarı/aşağı kayması, odaklayıcının tüpe montaj açısının da kontrol edilmesini gerektirebilir; odaklayıcı hafif yamuk monte edilmişse ikincili “doğru” göstermeye çalışırken bir noktada ilerleme sağlanamayabilir. Bu aşama genellikle bir kez doğru yapıldığında uzun süre korunur; ancak teleskop darbe aldıysa, mekanik parçalar değiştirildiyse veya yeni bir odaklayıcı takıldıysa yeniden kontrol edilmesi gerekir.

İkincil aynanın konumu doğruya getirildikten sonraki aşama, ikincil aynanın eğimini ayarlayarak odaklayıcı ekseninin birincil aynanın merkez işaretine bakmasını sağlamaktır. Sight tube üzerinde nişangâh çizgileri bulunuyorsa bu çizgiler birincil aynanın merkez işaretiyle çakıştırılır ve ikincil aynanın eğim vidaları çok küçük adımlarla ayarlanır. Birincil aynanın merkez işareti, odaklayıcı ekseninde tam ortada görünene kadar bu işlem sürdürülür. Bu aşamada sık yapılan hatalardan biri ikincil aynanın rotasyonunun (kendi ekseni etrafındaki dönüklüğünün) yanlış olmasıdır. Rotasyon hatalıysa, eğim vidalarıyla merkez işareti belirli bir noktaya getiriliyor gibi görünse bile birincil ayna yansıması simetrik bir geometri oluşturmaz; bu durumda ikincil ayna çok hafif gevşetilerek rotasyon düzeltilir ve eğim ayarı yeniden yapılır.

Newtonian sistemin performansını asıl belirleyen adım ise birincil aynanın optik eksenini odaklayıcı ekseniyle çakıştıran hassas eğim ayarıdır. Bu aşamada Cheshire odaklayıcıya takılır ve görüntüde birincil aynanın merkez işareti ile Cheshire’ın referans deseni birlikte izlenir. Birincil aynanın arkasındaki kolimasyon vidaları küçük hareketlerle çevrilerek merkez işaretinin referans desenle üst üste gelmesi sağlanır. Ayar yapılırken bir vidayı aşırı uçlara zorlamak yerine, iki veya üç vida arasında dengeli bir düzenleme yapmak daha stabil sonuç verir. İşlem tamamlandığında desenlerin eşmerkezli görünmesi ve merkez işaretinin tam ortada yer alması beklenir.

Kolimasyon doğru yapılsa bile doğru odaklama gerçekleştirilmeden beklenen keskinliğe ulaşmak mümkün değildir. Görsel gözlemde odaklama için parlak bir yıldız veya Ay kenarı gibi yüksek kontrastlı bir hedef seçilir; odak yavaşça ayarlanır ve yıldız görüntüsünün en küçük, en keskin noktaya ulaştığı konum optimum odak olarak kabul edilir. Kamera ile yapılan uygulamalarda ise sensör üzerinden büyütme/zoom kullanılarak yıldız görüntüsünün boyutu ve simetrisi izlenir; yıldızın en küçük ve en simetrik olduğu noktada odak sabitlenir ve mümkünse odak kilidi uygulanır. Odaklamada mekanik boşluklar kritik bir etkendir; odaklayıcıda oynama varsa odak kısa sürede kaçabilir ve oturumlar arasında görüntü kalitesi tutarsız hale gelebilir. Bu nedenle odaklayıcının mekanik sağlamlığı, pratikte kolimasyon kadar önemli bir unsurdur ve veri seti üretiminde standardizasyon için özellikle dikkate alınmalıdır.

3.1.1.4. KOLİMASYONUN DOĞRULANMASI: YILDIZ TESTİ, GÖRSEL VE FOTOĞRAFİK GÖSTERGELER

Kolimasyonun gerçek gözlem koşullarında doğru yapılıp yapılmadığını anlamanın en güvenilir yollarından biri yıldız testidir. Bu yöntemde gökyüzünde parlak ve tekil bir yıldız seçilerek yüksek büyütmeye geçilir. Ardından yıldız çok az odak dışına alınır ve oluşan dairesel halkaların simetrisi incelenir. Kolimasyon iyi ise halkalar merkezlenmiş ve simetrik görünür; kolimasyon kötü ise merkezdeki gölge kayar ve halkalar belirgin şekilde asimetrikleşir. Yıldız testi uygulanırken atmosferik koşulların (seeing) önemli bir değişken olduğu unutulmamalıdır. Seeing kötü olduğunda halkalar “zıplıyor” gibi görünebilir ve bu durum kolimasyon hatasıyla karıştırılabilir. Bu nedenle yıldız testi, teleskop termal dengeye geldikten sonra ve mümkünse gökyüzünün daha stabil olduğu zaman aralıklarında yapılmalıdır.

Kolimasyon sorunları çoğu zaman yalnızca testle değil, gözlemsel ipuçlarıyla da kendini belli eder. Örneğin görüntü alanının merkezindeki yıldızlar dahi kuyruklu veya uzamış görünüyorsa kolimasyonun kontrol edilmesi gerekir. Benzer şekilde gezegen detayları beklenenden silikse, odak doğru görünse bile optik hizalama yeniden değerlendirilmelidir. Ay gözlemlerinde terminatör çizgisi gibi yüksek kontrastlı kenarlarda çiftlenme ya da belirgin bir yumuşama görülmesi de hizalama veya odaklama ile ilişkili bir probleme işaret edebilir.

Fotoğrafik çıktılar ise kolimasyonun daha sistematik şekilde yorumlanmasına imkân verir. Çerçevenin bir tarafındaki yıldız şekilleri diğer tarafa göre belirgin biçimde farklılaşıyorsa, yalnızca kolimasyon değil sensör düzlemi ile optik eksen ilişkisi de birlikte ele alınmalıdır. Bunun yanında, görüntü merkezinde bile yıldızların noktasal olmaktan uzak olması kolimasyon hatasına veya odaklayıcı mekanizmada bir mekanik probleme işaret edebilir.

Bu tez kapsamında geliştirilen teleskop tabanlı sistemde kolimasyon, yalnızca ilk kurulum aşamasında yapılan tek seferlik bir işlem olarak değil, veri kalitesini standardize eden düzenli bir saha rutini olarak ele alınmıştır. Önerilen yaklaşımda öncelikle laboratuvar veya ev ortamında ayrıntılı kolimasyon yapılır; ikincil ayna merkezleme ve hedefleme adımlarının ardından birincil aynada hassas ayar gerçekleştirilir. Sahaya çıkmadan önce kısa bir kontrol ile birincil aynada hızlı bir Cheshire doğrulaması yapılır. Saha kurulumunda teleskop kurulduktan sonra kısa bir yıldız testi uygulanarak hizalamanın gerçek gözlem koşullarında da doğru sonuç verdiği doğrulanır. Veri toplamaya geçmeden önce, özellikle ortam sıcaklığında belirgin bir değişim varsa, teleskobun termal dengeye gelmesi için kısa bir süre beklenir ve ardından yeniden kısa bir kontrol yapılır. Ayrıca farklı günlerde toplanan verilerin karşılaştırılabilirliğini artırmak için her oturumun başlangıcında aynı kontrol adımlarının tekrarlanması hedeflenir. Bu disiplin, yapay zekâ tabanlı tanıma veya veri seti üretimi süreçlerinde görüntü kalitesindeki dalgalanmaların modele yansımasını azaltır ve aynı sınıftaki nesnelerin daha tutarlı görünmesine katkı sağlar.

Uygulamada sık karşılaşılan durumlardan biri, optik bileşenlerin “ortalanmış” görünmesine rağmen görüntünün hâlâ yeterince net olmamasıdır. Bu durumda teleskop termal dengeye gelmemiş olabilir, seeing koşulları kötü olabilir veya odaklayıcıda mekanik boşluk bulunabilir. Ayrıca birincil ayna çok sıkı tutuluyorsa yüzey gerilimi oluşarak görüntü kalitesini düşürebilir. Bu tür durumlarda termal denge için zaman tanınması, odaklayıcıdaki boşluğun kontrol edilmesi ve ayna klemplerinin aşırı sıkıysa gevşetilmesi önerilir; sonrasında yıldız testi tekrar edilerek durum doğrulanır.

Bir diğer yaygın sorun, ikincil ayarın bir türlü simetrik görünmemesidir. Bunun nedeni ikincil aynanın rotasyonunun hatalı olması, örümcek (spider) kollarının eşit gerginlikte olmaması veya odaklayıcının tüpe tam dik monte edilmemiş olması olabilir. Bu senaryoda ikincil aynanın rotasyonu yeniden kontrol edilir, spider gerginliği dengelenir ve gerekirse odaklayıcı montaj açısı incelenir.

Bazı durumlarda lazer kolimatör “doğru” bir hizalama gösterirken yıldız testinin “kötü” sonuç vermesi mümkündür. Bu çelişkinin kaynağı lazer kolimatörün kendi doğruluğunun bozuk olması, odaklayıcıya oturma toleranslarının lazeri yanıltması veya ikincil hedefleme aşamasındaki küçük bir hatanın büyüyerek etkili hale gelmesi olabilir. Bu nedenle lazer yönteminin daha çok hızlandırıcı bir araç olarak görülmesi, nihai doğrulamanın Cheshire ve yıldız testi gibi pasif yöntemlerle yapılması daha güvenilir bir yaklaşım sağlar.

Kolimasyonun sık sık bozulması ise genellikle mekanik kaynaklıdır. Mekanik gevşeklik, ayna hücresi esnemesi veya odaklayıcının oynaması gibi problemler buna sebep olabilir; ayrıca tüp farklı açılarda eğilme (fleks) gösterebilir. Bu durumda bağlantı elemanları kontrol edilir ve kritik gözlem öncesinde teleskop, hedefe bakılan açıya yakın bir konumdayken kolimasyonun yeniden doğrulanması önerilir.

Newtonian teleskoplarda ikincil ayna, spider adı verilen ince kollarla taşınır. Bu yapı özellikle parlak yıldızlarda görülen “çapraz ışınlar” (diffraction spikes) üretir ve bu izler zaman zaman kolimasyon hatası sanılabilir. Ancak bu durum, optik hizalamadan ziyade mekanik destek geometrisinden kaynaklanan fiziksel bir optik etkidir. Dolayısıyla kolimasyon mükemmel olsa bile difraksiyon izleri tamamen kaybolmayabilir. Görüntü kalitesini artırmak için spider geometrisinin optimize edilmesi, yani kolların kalınlığı, sayısı ve konumlandırmasının düzenlenmesi bir yaklaşım sunar. Bunun yanında bazı tasarımlarda spider kollarına eklenen özel profiller veya apodizer benzeri çözümlerle difraksiyon izlerinin şiddeti azaltılabilir. Bu tez bağlamında konu iki açıdan önem taşır: Görüntüdeki çizgisel izlerin yanlışlıkla “kolimasyon sorunu” olarak yorumlanmasını önlemek ve görüntü işleme ile veri seti üretimi aşamalarında parlak yıldız çevresindeki çizgisel yapıların algoritmaları etkileme riskine dikkat çekmek. Bu nedenle kolimasyon süreci doğru yapıldıktan sonra görüntü hâlâ belirgin difraksiyon izleri içeriyorsa, bunun hizalama hatası değil, spider kaynaklı difraksiyon etkisi olabileceği değerlendirilmelidir.

Newtonian teleskoplarda “mercek ayarı” olarak ifade edilen uygulama, pratikte kolimasyon + odaklama süreçlerinin birleşimidir. Kolimasyon; ikincil aynanın odaklayıcı altında doğru konumlandırılması, ikincil eğimin birincil merkeze yönlendirilmesi ve birincil aynanın hassas eğim ayarı adımlarından oluşur. Bu adımlar doğru uygulandığında teleskobun keskinlik ve kontrast performansı maksimuma çıkar; aynı zamanda görüntü işleme ve yapay zekâ tabanlı tanıma süreçleri için daha tutarlı ve kaliteli veri üretimi sağlanır. Son doğrulamanın yıldız testiyle yapılması, saha koşullarında güvenilir bir performans standardı oluşturur. Ek olarak, kolimasyon dışında kalan spider difraksiyonu gibi mekanik kaynaklı optik etkiler de görüntü değerlendirmesinde ayrıca dikkate alınmalıdır.

3.1.2. GÖRÜNTÜLEME BİRİMİ

Tez başlangıç aşamasında IMX477 gibi yüksek performanslı kamera modülleri değerlendirilmiş olsa da, maliyet-etkinlik kriterleri doğrultusunda ESP32-CAM modülü sisteme entegre edilmiştir. IMX477 sensörünün sunduğu yüksek çözünürlük, geniş dinamik aralık ve düşük gürültü değerleri göz önünde bulundurulmuş; ancak toplam sistem maliyetini önemli ölçüde artırması, güç tüketiminin daha yüksek olması ve özellikle taşınabilir bir gözlem düzeni hedefleyen araştırma kapsamında ek donanım gereksinimleri doğurması nedeniyle sistem tasarımından çıkarılması uygun görülmüştür. Buna karşın ESP32-CAM modülü, düşük çözünürlüklü olmasına rağmen gezegen gibi parlak gök cisimlerinin görüntülenmesi için yeterli performans sunmakta, özellikle parlaklık seviyesi yüksek hedeflerde net görüntüler oluşturabilmekte ve sistemin kompakt, düşük maliyetli, enerji verimli bir yapı kazanmasına katkı sağlamaktadır.

ESP32-CAM modülünün tercih edilme nedenlerinden biri de sistemin taşınabilirlik ve erişilebilirlik prensipleri gözetilerek tasarlanmasıdır. Modülün küçük form faktörü sayesinde hem teleskop üzerine ek yük bindirilmemekte hem de kullanım sırasında denge problemleri oluşmamaktadır.

Ayrıca modülün yerleşik Wi-Fi özelliği, verilerin anlık olarak Raspberry Pi’ye veya yerel ağa aktarılmasını kolaylaştırmakta; kablo yoğunluğunu azaltarak teleskop çevresindeki düzeneklerin sade kalmasını sağlamaktadır. Bu özellik, özellikle gece gözlemlerinde sistemin pratik kullanımını artırmakta ve kurulum süresini kısaltmaktadır.

Kameranın gövdeye entegrasyonu, optik eksen ile sensör düzlemi arasında hizalama hatalarını en aza indirmek amacıyla 3D yazıcı ile üretilmiş özel bir adaptör aracılığıyla yapılmıştır. Bu adaptör, teleskopun odak düzlemi ile ESP32-CAM’in sensör yüzeyi arasında doğru mesafenin korunmasını sağlayacak şekilde tasarlanmış, optik eksende oluşabilecek sapmaların azaltılması için tolerans değerleri göz önünde bulundurularak üretilmiştir. Üretim sırasında teleskopun odak noktasına ulaşabilmesi için gerekli geri odak aralığı dikkate alınmış; modül gövdeye mekanik olarak sağlam bir biçimde bağlanırken titreşim kaynaklı görüntü kayıplarını en aza indirecek bir yapıda monte edilmiştir.

Ayrıca adaptörün 3D baskı yöntemiyle üretilmiş olması, farklı sensörlerin veya farklı lens yapılandırmalarının gelecekte sisteme entegre edilebilmesine olanak tanıyan esnek bir platform sağlamıştır. Bu durum, tez kapsamında donanımın kolayca değiştirilebilir, geliştirilebilir ve çeşitli gözlem koşullarına uyarlanabilir olmasını mümkün kılmıştır. Böylece ESP32-CAM, yalnızca ekonomik ve pratik bir çözüm sunmakla kalmamış, aynı zamanda araştırma altyapısı üzerinde yapılabilecek gelecekteki genişletme çalışmalarının da önünü açmıştır.

3.1.3. MİKRODENETLEYİCİ VE KONTROL BİRİMLERİ

Sistemde teleskopun otonom olarak hareket edebilmesi için iki temel mikrodenetleyici birimi kullanılmıştır. Bu birimler, hem farklı görevlerin dağıtılmasını sağlamakta hem de sistemin çalışma sürekliliğini güvence altına alan yedekli bir yapı oluşturmaktadır.

Birinci kontrol birimi olan Raspberry Pi, görüntü işleme, sınıflandırma, veri kaydı, karar verme mekanizmaları ve yönlendirme komutlarının üretilmesinden sorumludur. Bu birim, sistemin “üst seviye kontrol merkezi” olarak çalışmakta; kamera modülünden gelen görüntüleri analiz etmekte, yapay zekâ modelini çalıştırmakta, tespit edilen gök cisminin konumunu yorumlamakta ve motorlara iletilmesi gereken yönlendirme talimatlarını hesaplamaktadır. Raspberry Pi’nin çok çekirdekli işlem yapısı, sistemin aynı anda hem görüntü işleme hem de sensör verisi değerlendirme işlemlerini gerçekleştirmesine olanak tanımakta; böylece gerçek zamanlı karar verme süreci kesintisiz sürdürülebilmektedir. Ayrıca bu birim, veri kaydının düzenli tutulması, meta verilerin dosyalanması ve ağ bağlantısı sağlandığında bu verilerin dış ortama aktarılması gibi operasyonel süreçlerde de

merkezi rol üstlenmektedir.

İkinci kontrol birimi olan Arduino Mega veya ESP32, düşük seviye görevler için sistemde görev almaktadır. Motor kontrolü, step motorların çalıştırılması, açısal hareket komutlarının uygulanması, hız kontrolü, yön değişikliklerinin senkronize edilmesi ve teleskopun fiziksel hareketlerinin doğru şekilde gerçekleştirilmesi bu birim tarafından yürütülmektedir. Aynı zamanda IMU ve GPS gibi sensörlerden gelen verilerin okunması, temel filtreleme işlemlerinin yapılması ve bu verilerin Raspberry Pi’ye güvenli şekilde iletilmesi de bu mikrodenetleyicinin sorumluluk alanındadır. Arduino Mega’nın kararlı ve deterministik çalışma yapısı ile ESP32’nin kablosuz iletişim ve yüksek hız avantajları göz önüne alındığında, bu kontrol biriminin sistem için esnek bir seçenek sunduğu görülmektedir.

Bu bileşen, Raspberry Pi’nin görev dışı kalması, kapanması veya kritik bir hata vermesi durumunda sistemi minimum işlevsellikle sürdürebilmek amacıyla aynı zamanda yedek bir kontrol modülü olarak yapılandırılmıştır. Böyle bir durumda sistem en azından teleskopun güvenli konuma alınmasını, motorların durdurulmasını veya temel bir yönlendirme işleminin gerçekleştirilmesini sağlayabilmektedir. Bu özellik, uzun gözlem oturumlarında sistem güvenliğini ve donanım bütünlüğünü korumak adına önemli bir tasarım tercihidir.

Her iki mikrodenetleyici de step motorlara gönderilecek hareket komutlarının üretilmesinden sorumludur ve ortak çalışma yapıları belirli bir görev paylaşımı üzerinden kurulmuştur. Raspberry Pi, hedef gök cisminin koordinatlarını hesaplayarak motorlara iletilmesi gereken hedef açıları belirlerken; Arduino veya ESP32 bu açılara ulaşmak için gerekli adım miktarını, hız profilini ve mikrostepping ayarlarını yönetmektedir. Böylece yönlendirme sürecinde hem yüksek seviye algoritmaların hem de düşük seviye kontrolün verimli biçimde entegre edilmesi sağlanmış; sistem hem doğru hem de tekrarlanabilir açı hareketleri üretebilen bir yapıya kavuşturulmuştur.

Bu iki mikrodenetleyici arasında veri alışverişi seri iletişim (UART), I2C veya Wi-Fi tabanlı protokoller aracılığıyla gerçek zamanlı olarak gerçekleştirilmiştir. Bu iletişim, tüm sistemin senkronize çalışması açısından kritik öneme sahiptir. Görüntü analizi sürecinde tespit edilen konum ile sensörlerden okunan gerçek yönelim arasındaki farklar sürekli olarak karşılaştırılmış; böylece teleskopun hedef gök cismini görüntünün merkezinde tutacak biçimde gerekli düzeltmeleri yapması mümkün olmuştur.

Sonuç olarak, bu iki birimin birlikte kullanılması sistemin hem esneklik hem de dayanıklılık kazanmasını sağlamış; otonom teleskop mimarisinin temelini oluşturan karar verme, konumlandırma ve hareket kontrolü süreçleri bu iki kontrol birimi tarafından sağlıklı şekilde yönetilmiştir.

3.1.4. MOTORLAR VE MOTOR SÜRÜCÜLERİ

Teleskop hareketi, iki eksenli alt-azimut yapıda çalışan step motorlar tarafından sağlanmıştır. Sistemde 17HS4401 model Nema17 step motorlar kullanılmış; motorların sürülmesi için TMC2208 model sürücü kartlarından yararlanılmıştır. Nema17 sınıfı motorlar kompakt yapıları, yüksek tork değerleri ve düşük maliyetleri nedeniyle amatör astronomi uygulamalarında yaygın olarak kullanılmakta olup, teleskoplarda gerekli olan yavaş ve kontrollü hareketleri üretmek için uygun bir çözüm sağlamaktadır. Bu motorların teleskop gövdesinde kullanılmasıyla her iki eksende hassas kontrol mümkün olmuş; sistemin hedef cismi otomatik takip edebilmesi için gerekli mekanik temel oluşturulmuştur.

TMC2208 motor sürücüleri ise seçildiği anda sistemin mekanik performansını belirgin şekilde iyileştiren bir bileşen olarak öne çıkmıştır. Bu sürücüler, motorların sessiz çalışması, akıcı hareket üretmesi, titreşim azaltma özellikleri ve mikrostepping desteği ile bilinir. Bu avantajlar astronomik gözlem gibi uzun pozlama veya düşük ışıkla gerçekleştirilen çalışmalarda kritik öneme sahiptir. Titreşimlerin minimuma indirilmesi, görüntülerin bulanıklaşmasını engelleyerek kameranın daha net kareler yakalamasını sağlamış; dolayısıyla modelin nesne tespit başarısını doğrudan olumlu yönde etkilemiştir.

Motor ve sürücü bileşenlerinin birlikte kullanılması, teleskop hareketlerinde doğruluk ve stabiliteyi artırmıştır. Özellikle otomatik takip sürecinde step motorların düzgün hız geçişleri ve kontrollü dur-kalk tepkileri, hedef cismin kadrajda kaymasını engellemiş ve uzun süreli gözlemlerde teleskopun sürekli yeniden hizalanması gereksinimini azaltmıştır. Alt-azimut yapının doğal sınırlamaları bulunsa da kullanılan motor-sürücü kombinasyonu sayesinde küçük düzeltmeler kesintisiz şekilde yapılabilmiş; bu durum, özellikle gezegenlerin görüntülenmesi sırasında hedefin kare merkezinde tutulmasına yardımcı olmuştur.

Motor sürücülerinin düşük gürültü ve yüksek hassasiyet sunması, sistemin gece gözlem ortamlarında dikkat dağıtıcı mekanik sesler üretmesini de engellemiştir. Bu özellik yalnızca kullanıcı deneyimini iyileştirmekle kalmamış, aynı zamanda motor titreşimlerinin teleskop borusu üzerinde oluşturabileceği küçük salınımların önüne geçmiştir. Sessiz çalışma modu, özellikle yıldız ve gezegen kaydı sırasında sensörün stabil bir görüntü yakalamasına katkıda bulunmuştur.

TMC2208’in sunduğu koruma devreleri de sistem güvenliği açısından önemli bir avantaj sağlamıştır. Akım sınırlama, ısınma kontrolü ve arıza durumunda otomatik kapanma gibi güvenlik önlemleri, motorların aşırı yük altında hasar görmesini engellemiş; uzun süreli kullanımda donanım dayanıklılığını artırmıştır. Bu koruma mekanizmaları, açık alanda yapılan gözlemlerde değişken sıcaklık ve nem koşullarına maruz kalan sistem bileşenlerinin daha güvenilir şekilde çalışmasına yardımcı olmuştur.

Ayrıca, 3D baskı parçaların hızlı prototipleme imkânı sayesinde saha testleri sırasında tespit edilen mekanik boşluk, hizalama sapması veya titreşim kaynakları kısa sürede giderilebilmiş; böylece iteratif iyileştirme döngüsü hızlandırılmıştır. Bununla birlikte, bağlantı elemanlarının parametrik tasarım yaklaşımıyla modellenmesi, farklı servo/motor modellerine ve farklı tork gereksinimlerine uyarlanabilirliği artırarak sistemin uzun vadeli bakım ve yükseltme süreçlerini de kolaylaştırmıştır.

Sonuç olarak kullanılan motorlar ve motor sürücüleri, sistemin otonom yönlendirme kabiliyetinin temel bileşenlerinden birini oluşturmuş; teleskopun doğruluk, kararlılık ve titreşimsiz hareket gereksinimlerini karşılayarak hem görüntü kalitesini hem de yapay zekâ tabanlı analiz süreçlerinin güvenilirliğini önemli ölçüde desteklemiştir.

3.1.5. KONUM VE YÖNELİM SENSÖRLERİ

Sistemin bulunduğu coğrafi konumun ve teleskopun yönelim açılarının doğru bir şekilde belirlenmesi, otonom gözlem sürecinin temel gerekliliklerinden biridir. Bu amaç doğrultusunda sistemde Neo-6M GPS modülü ile MPU6050 veya MPU9250 ivmeölçer–jiroskop birimleri birlikte kullanılmıştır. Neo-6M modülü, GPS uydularından elde ettiği sinyaller aracılığıyla teleskopun enlem, boylam ve yükseklik bilgilerini hassas biçimde belirlemekte; böylece gök cisimlerinin o anda bulunması beklenen konumlarının hesaplanmasında gerekli olan temel coğrafi koordinatları sağlamaktadır. GPS verilerinin düzenli güncellenmesi, özellikle ilk kalibrasyon aşamasında teleskopun dünya üzerindeki doğru konumunun sisteme tanıtılması açısından kritik öneme sahiptir.

Yönelim sensörü olarak kullanılan MPU6050 veya MPU9250 bileşenleri ise teleskopun mevcut eğim, dönüş ve ivme değerlerini ölçerek gerçek zamanlı yönelim bilgisinin elde edilmesini sağlamaktadır. Bu sensörler, ivmeölçer ve jiroskop verilerini bir araya getirerek teleskopun hem yatay hem de dikey eksendeki açısal durumunu belirler. Böylece sistem, teleskop başlangıç pozisyonunda iken gerçek bir referans noktası oluşturabilir ve hareket sırasında konum kaymalarını algılayarak gerekli düzeltmeleri gerçekleştirebilir.

Bu sensörlerden elde edilen konum ve yönelim verileri araştırma sürecinde üç temel alanda kullanılmıştır. İlk olarak, teleskopun başlangıç konumunun tanımlanmasında önemli rol oynamış; GPS ve IMU verilerinin birleştirilmesiyle sistemin otonom modda çalışabilmesi için gerekli temel referans oluşturulmuştur. İkinci olarak, gözlem yapılacak gök cisminin teorik konumu ile teleskopun mevcut yönelimi kıyaslanarak açısal fark hesaplanmış; böylece motorların ne kadar ve hangi yönde hareket etmesi gerektiği belirlenmiştir. Üçüncü olarak ise otonom takip sürecinde oluşabilecek yönelim kaymaları, titreşimler veya mekanik tolerans kaynaklı sapmalar sensör verileri ile tespit edilmiş ve sistem gerektiğinde mikro düzeltmeler yaparak hedef cismin merkezde tutulmasını sağlamıştır.

Neo-6M ve MPU serisi sensörlerin birlikte kullanılması, düşük maliyetli teleskop sistemlerinde sık karşılaşılan yönelim belirsizliklerinin büyük ölçüde giderilmesini sağlayarak otonom yönlendirme performansını artırmıştır. Bu yapı, sistemin her gözlem oturumunda doğruluğunu korumasını kolaylaştırmış, özellikle uzun süreli planet takip deneylerinde stabil bir çalışma elde edilmesine katkı sağlamıştır.

3.1.6. GÜÇ BİLEŞENLERİ VE EK DONANIMLAR

Sistem, açık alanda uzun süreli gözlem yapılabilmesine olanak tanıyan taşınabilir bir güç altyapısıyla donatılmıştır. Gözlem istasyonlarının çoğu şehir ışıklarından uzak bölgelerde kurulduğundan, enerji kaynağının güvenilir ve yeterli kapasiteye sahip olması sistemin kesintisiz çalışması için temel gerekliliktir. Bu doğrultuda kullanılan 3S Li-Po batarya, hem yüksek akım sağlayabilmesi hem de ağırlık açısından taşınabilirliğe uygun olması nedeniyle tercih edilmiştir. Li-Po bataryaların yüksek enerji yoğunluğu, motorlar, sensörler ve diğer bileşenlerin yaklaşık birkaç saat boyunca aralıksız çalışmasına imkân tanımıştır.

Bataryadan gelen enerjinin sistem bileşenlerine uygun seviyede dağıtılması için XL4016 DC–DC voltaj regülatörü kullanılmıştır. Bu regülatör, teleskop sisteminde yer alan farklı modüllerin gerektirdiği 5V ve 12V seviyelerini stabil şekilde sağlayarak bileşenlerin güvenli biçimde çalışmasını mümkün kılmıştır. Motor sürücüleri gibi yüksek akım gerektiren parçaların çalışması sırasında voltaj dalgalanmalarının oluşmaması, sistemdeki elektronik bileşenlerin kararlılığı için önemli bir avantaj olmuştur. Regülatörün ayarlanabilir yapısı, sistem tasarımı sırasında gerekli voltaj seviye optimizasyonlarının kolayca yapılmasına olanak tanımıştır.

Bataryanın sağlıklı bir şekilde şarj edilmesi ve batarya ömrünün korunması amacıyla iMax B6 şarj cihazı tercih edilmiştir. Bu cihaz, Li-Po bataryalar için gerekli olan hassas şarj algoritmalarını desteklemekte; aşırı şarj, aşırı deşarj ve hücre dengesizliği gibi batarya sağlığını olumsuz etkileyebilecek durumları engelleyerek bataryanın uzun ömürlü kullanımını güvence altına almaktadır. Açık alanda yapılan gözlemlerde bataryanın güvenli biçimde yönetilmesi, sistemin uzun süreli çalışması için kritik bir gereklilik olmuştur.

Sistemin mekanik bileşenlerinin montajı için 3D yazıcı ile üretilmiş özel parçalar kullanılmıştır. Bu parçalar arasında teleskop gövdesine kamera bağlamak için kullanılan adaptörler, motor bağlantı aparatları, dişli veya kayış mekanizmalarını taşıyan yapılar ve sensörlerin montajını kolaylaştıran destek bileşenleri bulunmaktadır. 3D baskı teknolojisi sayesinde sistem, prototipleme aşamasında hızlı bir şekilde uyarlanabilir hale gelmiş; farklı boyutlardaki motorlar, kameralar veya mekanik elemanların kolayca entegre edilebilmesi mümkün olmuştur. Bu esneklik, tez süresince yapılan testler sırasında ihtiyaç duyulan değişikliklerin hızlıca uygulanmasını sağlamış ve sistemin geliştirme sürecini önemli ölçüde hızlandırmıştır.

Ek donanımlar arasında kablolar, vidalar, montaj aparatları, güç dağıtım bileşenleri ve elektronik bağlantı elemanları yer almış; tüm bu bileşenler sistemin bütünlüklü ve güvenilir şekilde çalışmasını desteklemiştir. Mekanik ve elektronik parçaların uyum içinde çalışabilmesi için tüm bağlantılar dikkatle düzenlenmiş; açık alandaki sıcaklık, nem ve toz gibi çevresel etkenlere karşı yeterli dayanıklılığa sahip bir yapı oluşturulmuştur.

Sonuç olarak güç bileşenleri ve ek donanımlar, sistemin taşınabilirliğini, sürdürülebilirliğini ve uzun süreli gözlem koşullarına dayanıklılığını sağlayan kritik unsurlar olarak görev yapmış; teleskopun sahada kesintisiz ve güvenilir biçimde çalışabilmesine önemli katkı sunmuştur.

3.2. YAZILIM ALTYAPISI VE YAPAY ZEKÂ BİLEŞENLERİ

Sistemin otonom olarak çalışabilmesini sağlayan temel yapı, görüntü toplama, ön işleme, nesne tespiti, sınıflandırma, engel algılama, gözlemlenebilir alan oluşturma, hedef seçimi, açı hesaplama, motor sürme ve geri bildirim döngüsünü kapsayan çok katmanlı bir yazılım mimarisine dayanmaktadır. Bu mimari tasarlanırken sistemin düşük maliyetli donanımlarla uyum içinde çalışabilmesi, sensörlerin sınırlı çözünürlük ve doğruluk kapasitesinin doğru yorumlanabilmesi ve ESP32-CAM gibi kompakt bir kameranın ürettiği nispeten düşük kaliteli görüntülerin işlenebilir hale getirilmesi amaçlanmıştır. Bu nedenle yazılım altyapısının en kritik yönü, verilerin işlenme sırasının doğru belirlenmesi ve her bileşenin birbirine doğru şekilde bağlanmasıdır.

Görüntü toplama sürecinde ESP32-CAM, geniş bir açıya sahip olacak şekilde teleskop odak düzlemine yerleştirilmiş ve elde edilen kareler Raspberry Pi’ye aktarılmıştır. Bu aktarım sonrasında görüntüler, yapay zekâ modeline gönderilmeden önce mutlaka bir ön işleme sürecine tabi tutulmuştur. Özellikle gökyüzü gözlemleri sırasında parlaklık seviyeleri sürekli değiştiğinden, ham görüntüler doğrudan kullanılmaya uygun değildir. Bu nedenle yazılım ilk aşamada her karenin parlaklık ve kontrastını dinamik olarak düzenleyerek yüzey detayının belirginleşmesini sağlar. Arka plan gürültüsünün hafifletilmesi, sensör kaynaklı parlaklık lekelerinin azaltılması, düşük ışıkta oluşan beneklenme efektinin filtrelenmesi ve gökyüzündeki doğal gradyan geçişlerinin korunması ön işleme sürecinin önemli parçalarıdır. Böylece görüntüler hem engel algılama modülüne hem de gök cismi tespit algoritmalarına daha istikrarlı bir biçimde aktarılır.

Sistemin önemli bir bileşeni, gözlemlenebilir alanın belirlenmesi için çalışan hibrit engel tespit mekanizmasıdır. Bu mekanizma, hem parlaklık ve kenar yoğunluğu tabanlı klasik görüntü işleme yöntemlerini hem de heuristik tabanlı çözüm mantıklarını bir arada kullanır. Teleskop çevresi her zaman gökyüzüne tamamen açık olmayabileceği için yazılım, otonom gözleme başlamadan önce belirli bir aralıkta tarama yaparak engel haritası çıkarır. Kamera belirlenen açılarda döndürülür, alınan her görüntüde kenar yoğunluğu analiz edilir ve gökyüzüne özgü düşük kenar yapısı ile engellere özgü yüksek kenar yapısı arasındaki farklar yakalanır. Bazı açılarda parlaklık düşük veya görüntüde dokusal yoğunluk yüksekse sistem o açıyı engelli bölge olarak kaydeder. Böylece teleskop sadece gökyüzü açık kısımlarda çalışacak şekilde sınırlandırılır. Kullanıcı dilerse mobil uygulama üzerinden bu tarama sürecini tamamen geçebilir; özellikle açık ovada, çatısız alanlarda veya gökyüzü tamamen açık bir konumda gözlem yapılıyorsa bu modül devre dışı bırakılabilir.

Engel haritasının oluşturulmasının ardından yazılım, o anda konumlanılan noktada hangi gök cisimlerinin gerçekten gözlemlenebilir olduğunu hesaplar. GPS verisiyle elde edilen enlem-boylam bilgisi, gerçek zamanlı saat verisi ve gök cisimlerinin efemeris hesaplamaları bir araya getirilerek Ay, Mars, Jüpiter, Venüs, Satürn gibi parlak hedeflerin, ayrıca bazı parlak yıldızların ve uygun şartlarda belirli derin uzay cisimlerinin o anda gökyüzündeki konumu hesaplanır. Bu konumların ufka göre yüksekliği ve engel haritasıyla kesişimi kontrol edilir; engelli açılara denk gelen cisimler gözlemlenebilir listesine dahil edilmez. Böylece hem gereksiz hareketler önlenir hem de kullanıcıya yalnızca gerçekten gözlemlenebilir cisimler sunulur.

Nesne tespiti ve sınıflandırma süreci, hafif bir CNN tabanlı yapay zekâ modeline dayanmaktadır. Model, düşük çözünürlüklü görüntülerde çalışacak şekilde sadeleştirilmiş, gereksiz katmanlar çıkarılmış ve mobil cihazlarda yaygın kullanılan kompakt mimariler örnek alınarak optimize edilmiştir. Model özellikle parlak gök cisimlerine duyarlıdır ve Ay, Jüpiter gibi geniş parlaklık farkı oluşturan objeleri hızlı şekilde tanıyabilir. Çıktılar arasında cismin sınıfı, başarı oranı, görüntüdeki konumu, parlaklık değeri ve tespit zamanı yer alır. Bu bilgiler yönlendirme kararlarının temel girdisidir; özellikle cismin görüntü merkezinden uzaklığı hesaplanarak motorlara geri bildirim sinyali oluşturulur.

Yazılım mimarisinde tüm bu sürecin arka planında gerçek zamanlı bir kontrol döngüsü çalışmaktadır. Raspberry Pi, sürekli olarak yeni görüntü alır, modeli çalıştırır, gerekli düzeltmeleri hesaplar ve motor sürme birimine gereken komutları gönderir. Tüm modüller, kendi içinde bağımsız olmasına karşın veriler ortak bir “durum yöneticisi” (state manager) üzerinden paylaşılır. Böylece hem karar alma süreci hızlandırılır hem de donanım katmanındaki gecikmeler sistem bütünlüğünü etkilemez. Otonom gözlem sürecinin stabil ve kesintisiz çalışabilmesi için yazılım tasarımında hata tolerans mekanizmaları da eklenmiştir; beklenmeyen sensör davranışları, anlık GPS kaymaları veya anlık görüntü bozulmaları durumunda sistem bir sonraki döngüde kendini toparlayacak şekilde tasarlanmıştır.

3.2.1. YAZILIM MİMARİSİ VE KODLAMA YOL HARİTASI: YILDIZ–GEZEGEN TANIMA VE OTONOM GÖZLEM AKIŞI

Bu projede yazılım iki katmanlı tasarlanacaktır. AWS üzerinde çalışan ana servisler gözlem planlama, hedef listesi yönetimi, veri seti biriktirme ve model eğitimi gibi yüksek kaynak isteyen işleri üstlenirken; Raspberry Pi 5 üzerinde çalışan saha ajanı motor sürme, sensör okuma, görüntü alma ve düşük gecikmeli yerel çıkarım (inference) görevlerini yerine getirecektir. Böylece internet bağlantısının zayıf olduğu sahalarda dahi temel işlevler korunurken, bağlantı mevcut olduğunda daha zengin planlama ve daha güçlü model sürümleri otomatik devreye girecektir. AWS tarafında ham görüntülerin ve etiketlerin S3’e yazılması, mobil uygulamanın tek bir API üzerinden sistemle konuşması, S3’e güvenli yükleme/indirme için presigned URL yaklaşımının kullanılması hedeflenir.

RPi 5 tarafında ana dil Python olacaktır. Picamera2/libcamera katmanı üzerinden kamera kontrolü yapılır ve bu yapı, sahada önce Raspberry Pi Kamera Modülü V1.3 ile başlayıp daha sonra IMX477’ye geçildiğinde üst seviye akışın değişmeden korunmasına imkân verir. Servo motorlar 60 kg sınıfında olacağı için Raspberry Pi’nin GPIO’sundan doğrudan PWM üretmek yerine pratikte daha kararlı olan PCA9685 tabanlı bir PWM sürücü (I2C) ile sürmek önerilir. Bu sayede titreşim ve zamanlama dalgalanmalarının etkisi azaltılır, iki eksende (pan–tilt) pürüzsüz komut vermek kolaylaşır. NEO-7M GPS modülünden konum almak için RPi üzerinde seri port okuması pySerial ile yapılır; NMEA cümlelerini ayrıştırmak için pynmea2 kullanılır. MPU9250 IMU verisi I2C üzerinden okunur. Saha koşullarında servo hareketleri ve ortam etkileri ölçümü bozabileceği için IMU tarafında “orientation filter” uygulanır ve kontrol katmanı daha stabil bir yönelim girdisi ile beslenir.

Bu filtreleme, yazılımın kontrol kararlılığını artırdığı için otonom hedeflemede kritik rol oynar. RPi saha ajanının iç mantığı bir durum makinesi (state machine) yaklaşımıyla kurgulanır. Ajan sensörleri okur, hedef belirleme aşamasına geçer, hedefe yönelir, görüntüyü alır, yıldız ve gezegen tanıma modülünü çalıştırır, gerekirse mikro düzeltme uygular ve veriyi kaydeder veya aktarır. Bu yapı hem manuel mod (mobil uygulama hedef seçer) hem otomatik mod (sistem görünür hedef listesinden seçer) için aynıdır; sadece hedefin kaynağı değişir. Bağlantı kesilirse görüntü ve metaveriler yerelde kuyruklanır; bağlantı geldiğinde AWS’e toplu aktarım yapılır.

Şekil 3, Şekil 4 ve Şekil 5’de gerçek kodun “nasıl görüneceğini” göstermek için doğrudan projeye kopyalanabilir örnek iskeletlerdir.

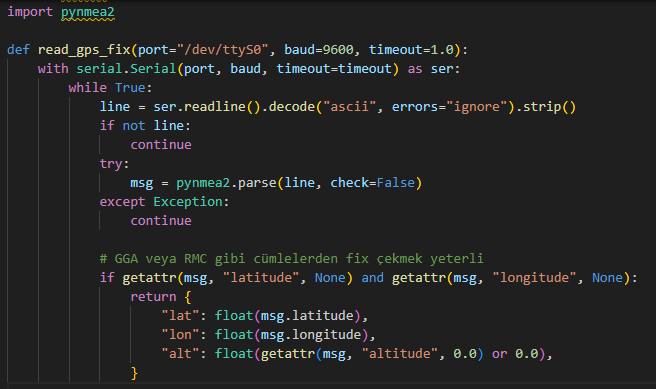
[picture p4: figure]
metin, ekran görüntüsü, yazılım, ekran, görüntüleme içeren bir resim Yapay zeka tarafından oluşturulmuş içerik yanlış olabilir.

Şekil 3. NEO-7M GPS Örnek Okuma Kodu

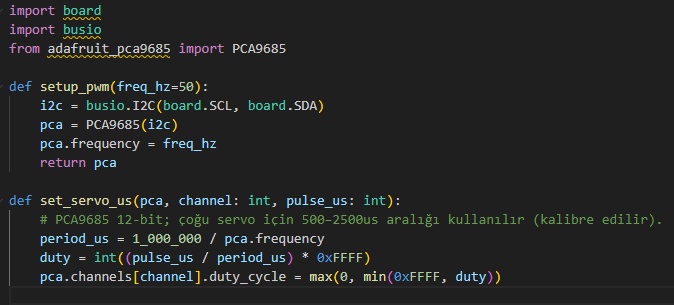
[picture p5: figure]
metin, ekran görüntüsü, yazılım, multimedya yazılımı içeren bir resim Yapay zeka tarafından oluşturulmuş içerik yanlış olabilir.

Şekil 4. Örnek Servo Sürme Kodu

Bu katmanda 60 kg servo kullanımı nedeniyle güç beslemesi ayrıca tasarlanır. Yazılım tarafında önemli olan, servo komutlarının anlık sıçramalar yerine hız limitli bir rampayla uygulanmasıdır. Bu sayede titreşim azalır ve yıldız merkezleme döngüsü daha kararlı olur.

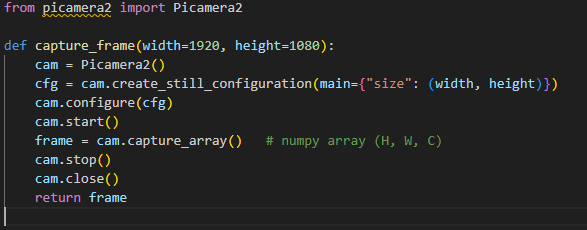
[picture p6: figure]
metin, ekran görüntüsü, yazılım, yazı tipi içeren bir resim Yapay zeka tarafından oluşturulmuş içerik yanlış olabilir.

Şekil 5. Örnek Kare Yakalama Kodu

Yıldız tanıma tarafında amaç ikiye ayrılır: görüntüde yıldızları güvenilir şekilde bulmak ve görüntü kalitesi/odak gibi metrikleri çıkarmak; gerekiyorsa hedef doğrultusunu iyileştirmek için küçük düzeltmeler üretmek. Bu projede yazılımsal olarak sağlam yaklaşım, yıldızları “noktasal kaynak” gibi tespit eden hazır astronomi araçlarını kullanmaktır. Photutils bu iş için uygun bir altyapı sağlar. RPi sürümünde photutils kullanımı mümkündür; performans baskısı olursa OpenCV tabanlı basit tepe tespiti (eşikleme ve blob tespiti gibi) yedek plan olarak eklenir.

Bu katmanda elde edilen yıldız merkez koordinatları, takip döngüsüne geri besleme sağlar. Hedeflenen parlak yıldızın görüntü merkezinden sapmasına göre servo düzeltmesi üretilir. Böylece IMU/GPS tabanlı kaba yönlendirme üzerine görüntü tabanlı ince düzeltme eklenmiş olur.

Gezegen tanıma modülü, saha ajanında hafif çalışacak şekilde tasarlanır. Uygulamada iki aşamalı bir kurgu tercih edilir: önce görüntüden hedef bölgeyi (ROI) çıkaran ön işleme katmanı, ardından ROI’yi sınıflandıran CNN modeli. ROI çıkarımı için kaba yaklaşım genellikle yeterlidir; gezegenler parlak ve belirgin disk yapısına sahip olduğundan merkezdeki parlak bölgeyi bulup kırpmak çoğu senaryoda işe yarar. Ardından CNN modeli ROI’yi “Jüpiter / Satürn / Mars / Venüs / Ay / yıldız (noktasal) / boş gürültü” gibi sınıflara ayırır. Modelin veri seti, sistemin ürettiği gerçek görüntülerle iteratif olarak güçlendirilir ve bu süreçte AWS tarafı veri seti biriktirme ve eğitim otomasyonu açısından kritik rol oynar.

RPi tarafında inference için iki seçenek sürdürülebilir şekilde yürütülebilir: TensorFlow Lite ile tflite-runtime kullanmak veya ONNX Runtime ile ONNX modeli çalıştırmak. TFLite yaklaşımı edge cihazlarda kurulum ve kaynak tüketimi açısından genellikle daha hafiftir; ONNX yaklaşımı ise eğitim ve dağıtım hattında esneklik kazandırabilir. Şekil 6’da örnek TFLite iskelet kodlarını görebilirsiniz.

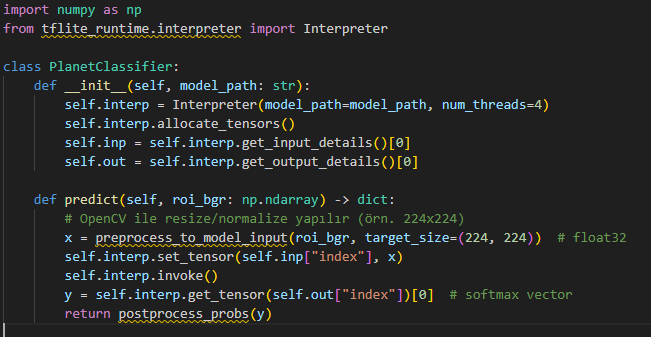
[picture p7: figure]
metin, ekran görüntüsü, yazılım, yazı tipi içeren bir resim Yapay zeka tarafından oluşturulmuş içerik yanlış olabilir.

Şekil 6. RaspberryPi’de TFLite Inference Örnek İskeleti

Bu sınıfın yanında preprocess_to_model_input() fonksiyonu OpenCV ile yazılır (yeniden boyutlandırma, kanal sırası, normalize). RPi saha ajanında tipik paketler; picamera2, opencv-python, numpy, tflite-runtime veya onnxruntime, pyserial, pynmea2, servo/sürücü için adafruit_pca9685 ve IMU için seçilen sürücü kütüphanesidir.
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

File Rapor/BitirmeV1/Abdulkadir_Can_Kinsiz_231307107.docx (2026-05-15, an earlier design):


KOCAELİ ÜNİVERSİTESİ

Fen Bilimleri Enstitüsü

BİLİŞİM SİSTEMLERİ MÜHENDİSLİĞİ ANABİLİM DALI

Yapay Zekâ Destekli Otomatik Teleskop Yönlendirme, Gök Cismi Tanıma ve Gök Cismi Veri Seti Oluşturma Platformu

ABDULKADİR CAN KİNSİZ

Dr. Öğr. Üyesi Önder Yakut

LİSANS TEZİ

~~Kocaeli,~~ ~~202~~~~5~~

Onay Sayfası

Etik Beyan ve Araştırma Fonu Desteği

Kocaeli Üniversitesi Fen Bilimleri Enstitüsü tez yazım kurallarına uygun olarak

hazırladığım bu tez/proje çalışmasında,
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

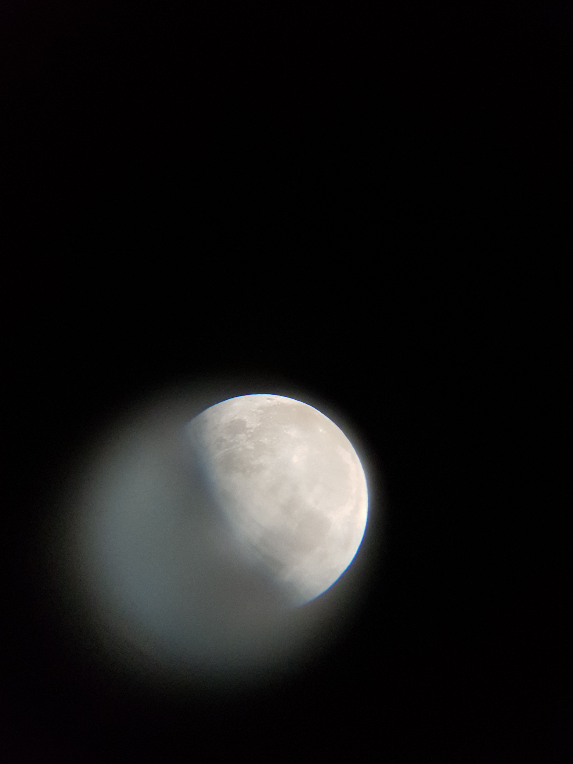
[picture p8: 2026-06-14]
Web/uploads/20260530_204006_82ee96442df3.jpg

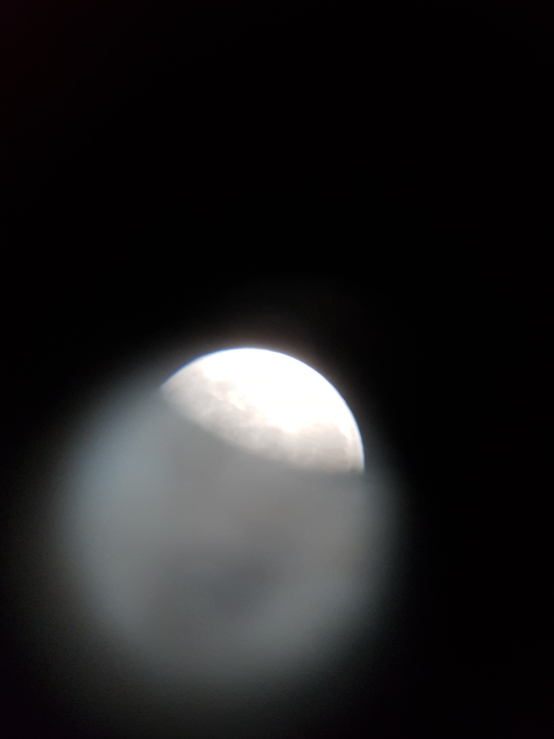
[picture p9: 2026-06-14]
Web/uploads/20260530_205302_538c6ff7b594.jpg

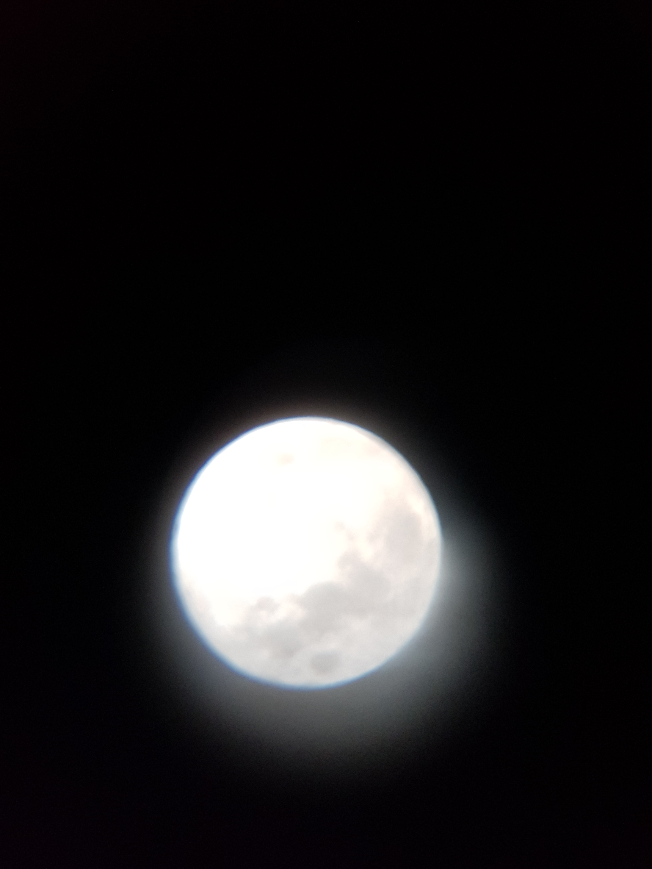
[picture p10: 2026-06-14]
Web/uploads/20260530_205305_a3ff17c6ac64.jpg

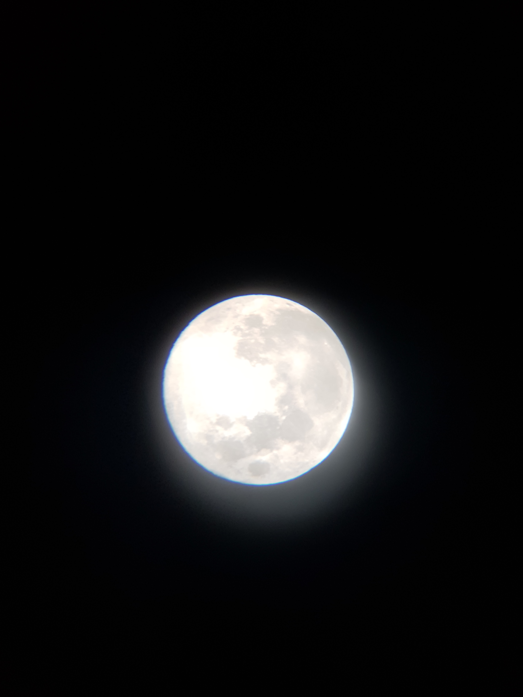
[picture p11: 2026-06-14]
Web/uploads/20260530_211749_a3cb2ab1a4e7.jpg

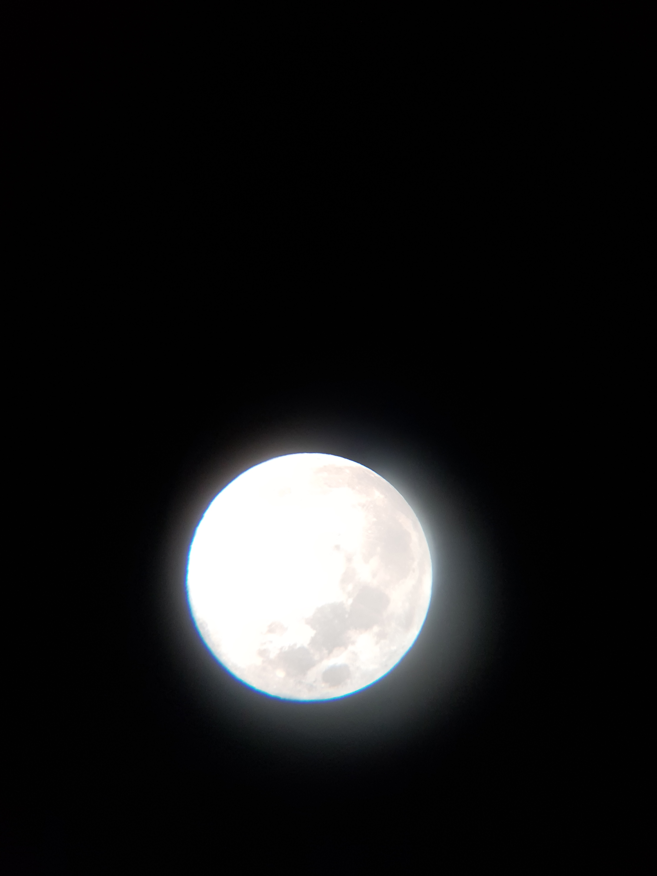
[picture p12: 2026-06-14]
Web/uploads/20260530_204005_c9964e686e12.jpg

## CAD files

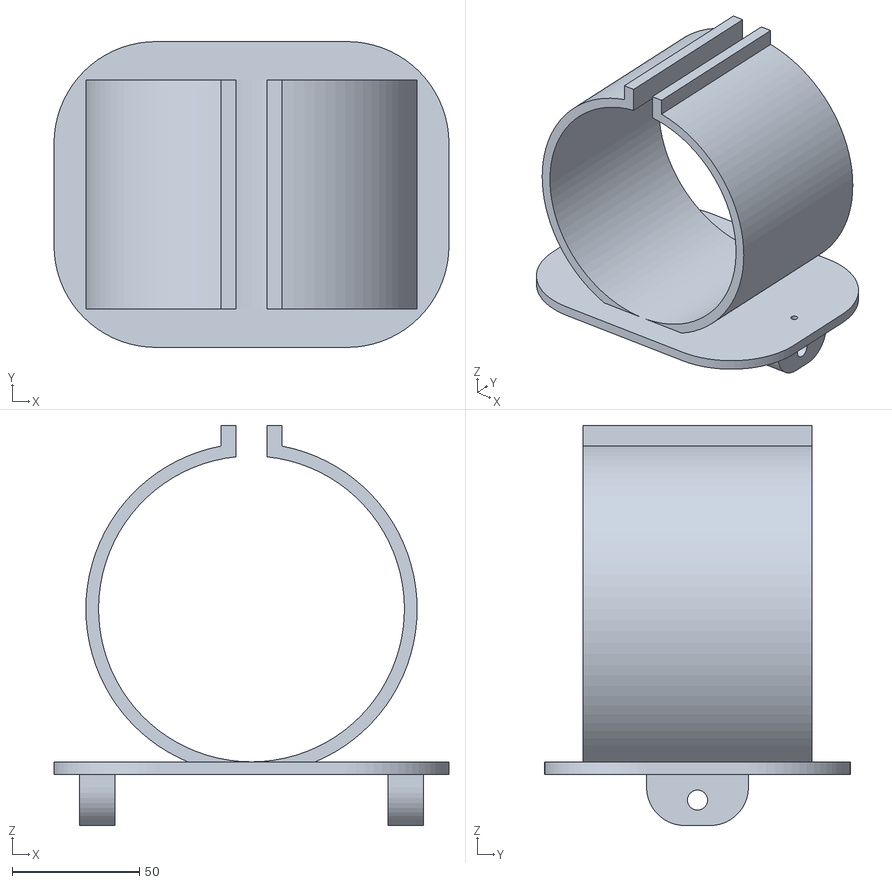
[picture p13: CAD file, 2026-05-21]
Rapor/BitirmeV2/3D Tasarımlar/teleskop üstü son.stl
155.0 x 120.0 x 157.0

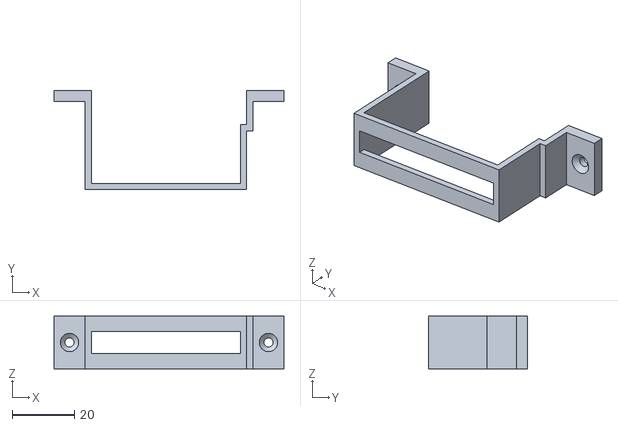
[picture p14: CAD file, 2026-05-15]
Rapor/BitirmeV2/3D Tasarımlar/servo tutucu 1.stl
73.9 x 31.9 x 17.0

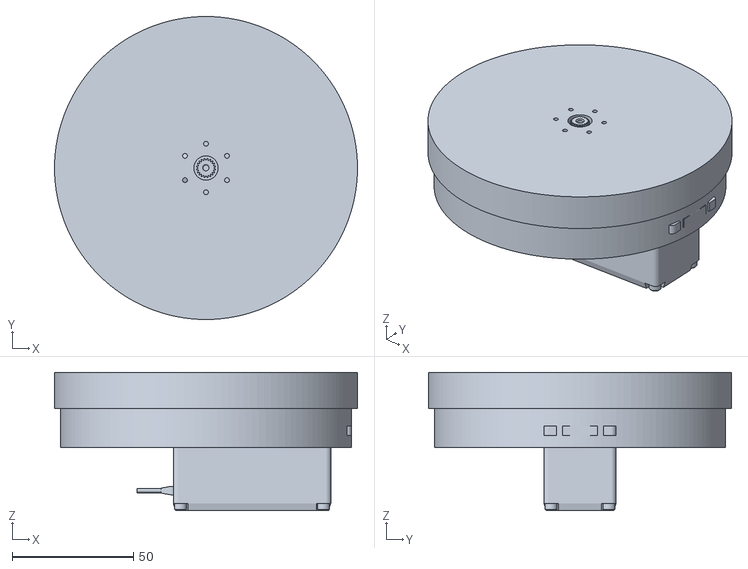
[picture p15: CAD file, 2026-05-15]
Rapor/BitirmeV2/3D Tasarımlar/360 altın üstü plaka (Montaj).stl
125.0 x 125.0 x 57.0

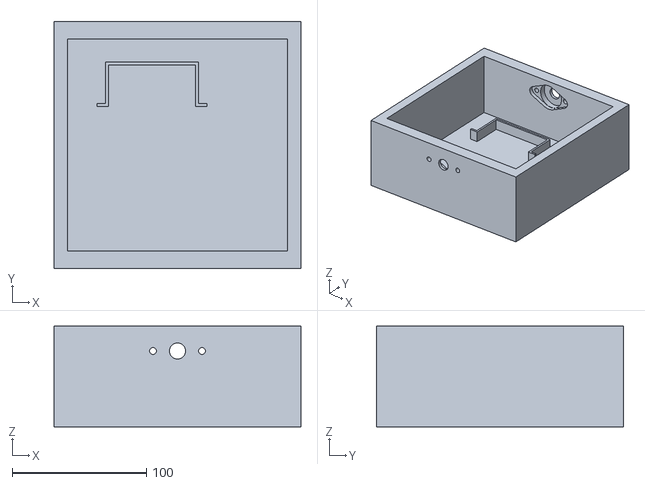
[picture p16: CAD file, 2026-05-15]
Rapor/BitirmeV2/3D Tasarımlar/Alt_Parca.stl
184.0 x 184.0 x 75.0

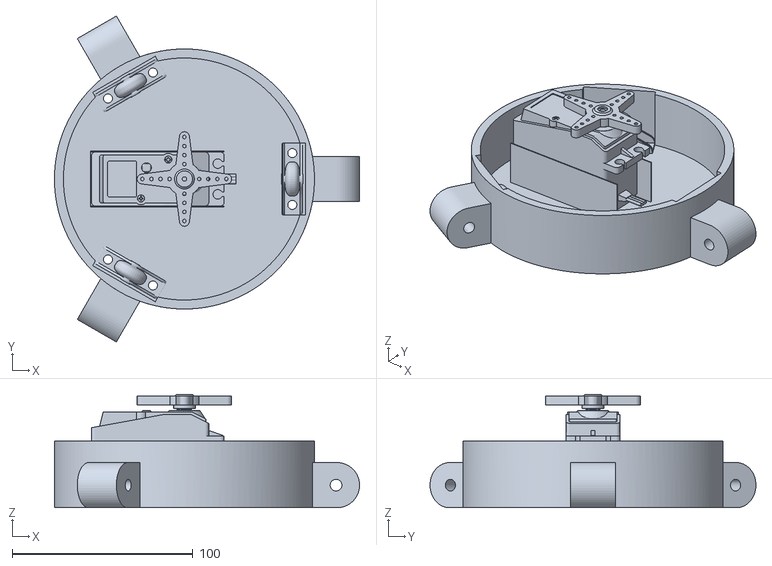
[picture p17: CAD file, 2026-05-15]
Rapor/BitirmeV2/3D Tasarımlar/alt plaka servolu.stl
169.0 x 180.5 x 62.8

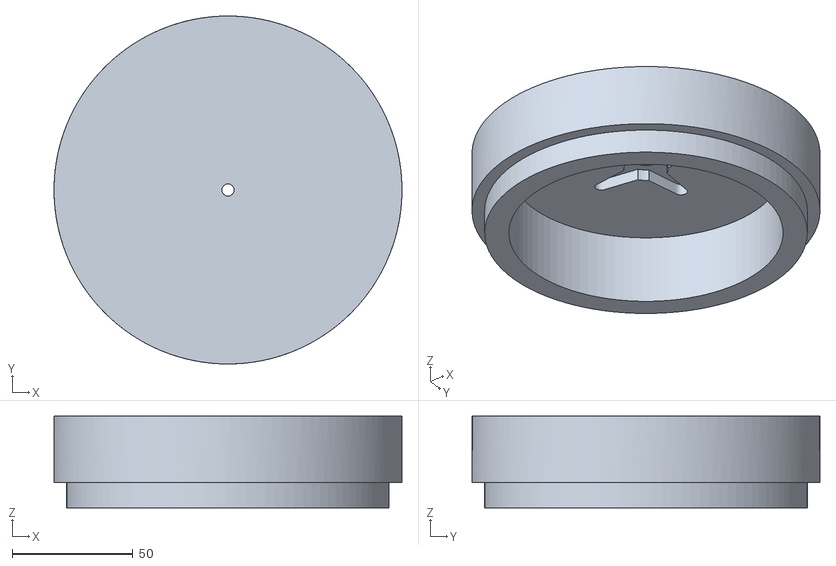
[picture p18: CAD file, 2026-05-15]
Rapor/BitirmeV2/3D Tasarımlar/360 üst parça.stl
144.0 x 144.0 x 37.9

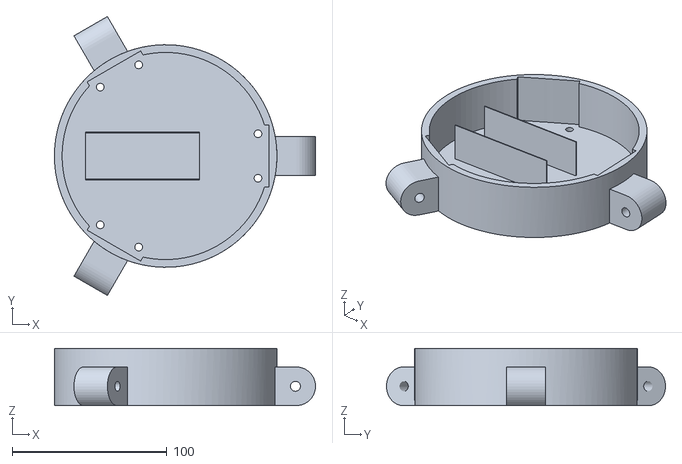
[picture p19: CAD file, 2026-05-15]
Rapor/BitirmeV2/3D Tasarımlar/telescope alt2 360.stl
169.0 x 180.5 x 37.0

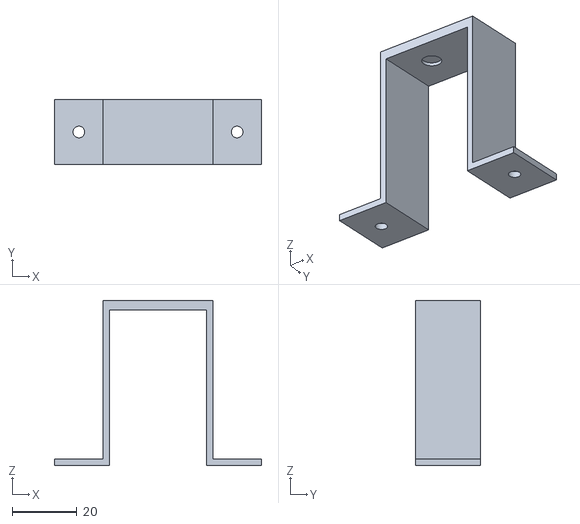
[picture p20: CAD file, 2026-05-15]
Rapor/BitirmeV2/3D Tasarımlar/servo tutucu 2.stl
63.7 x 20.0 x 50.8

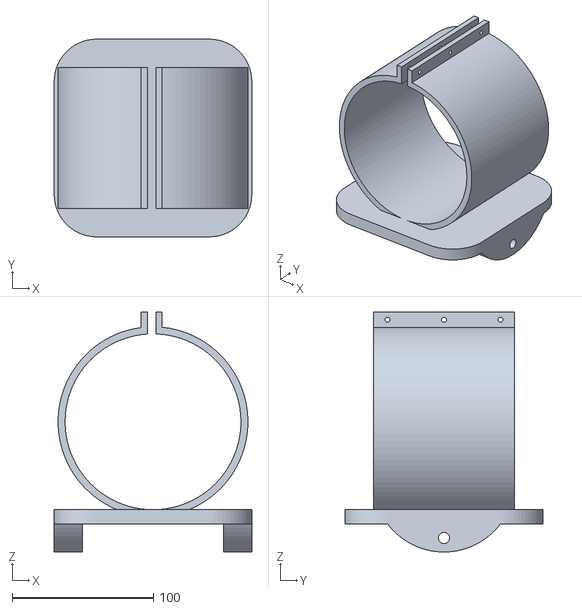
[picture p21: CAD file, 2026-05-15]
Rapor/BitirmeV2/3D Tasarımlar/Teleskop_Mount.stl
140.0 x 140.0 x 170.0

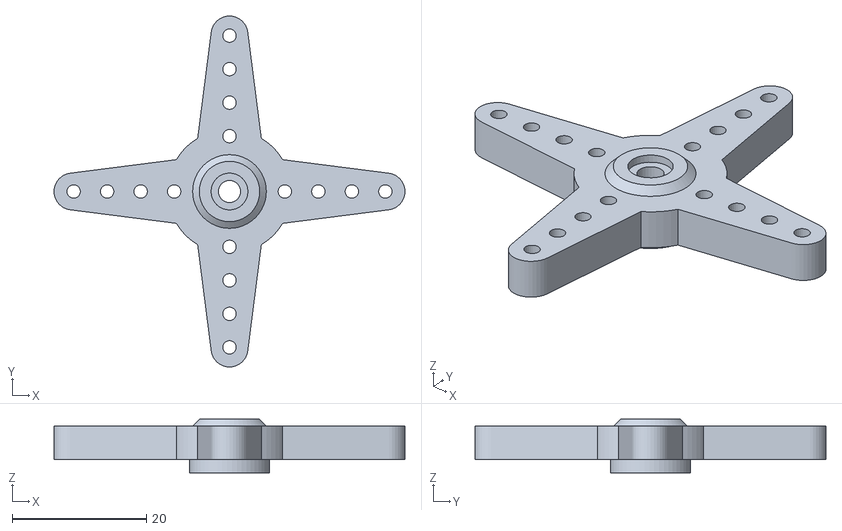
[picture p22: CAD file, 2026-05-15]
Rapor/BitirmeV2/3D Tasarımlar/servo ucu 2.stl
52.4 x 52.4 x 8.00

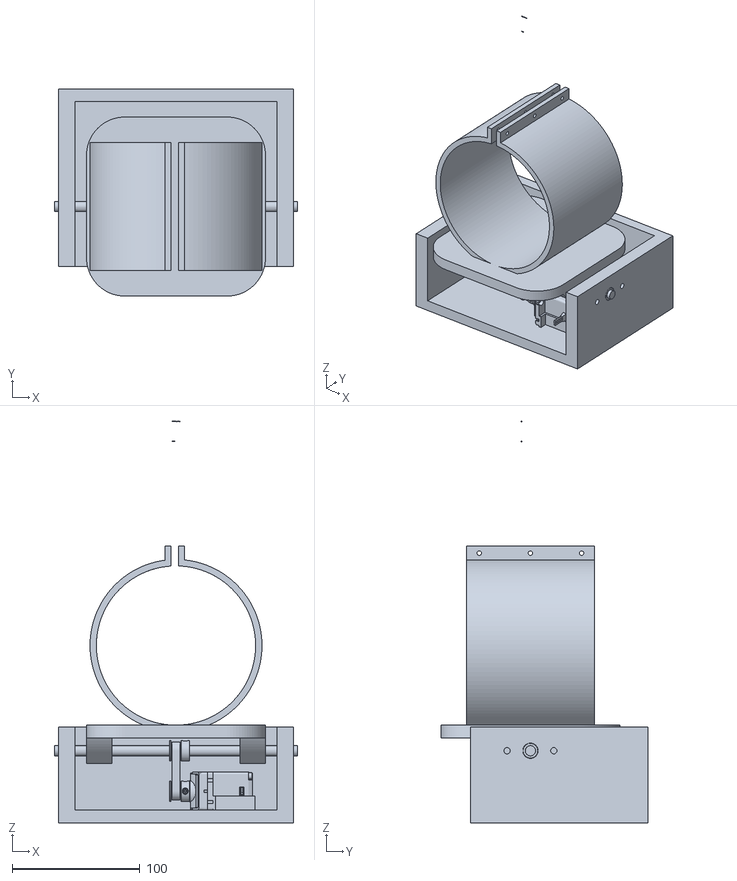
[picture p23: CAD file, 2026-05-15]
Rapor/BitirmeV2/3D Tasarımlar/teleskop montaj kesit.stl
190.0 x 162.0 x 314.3

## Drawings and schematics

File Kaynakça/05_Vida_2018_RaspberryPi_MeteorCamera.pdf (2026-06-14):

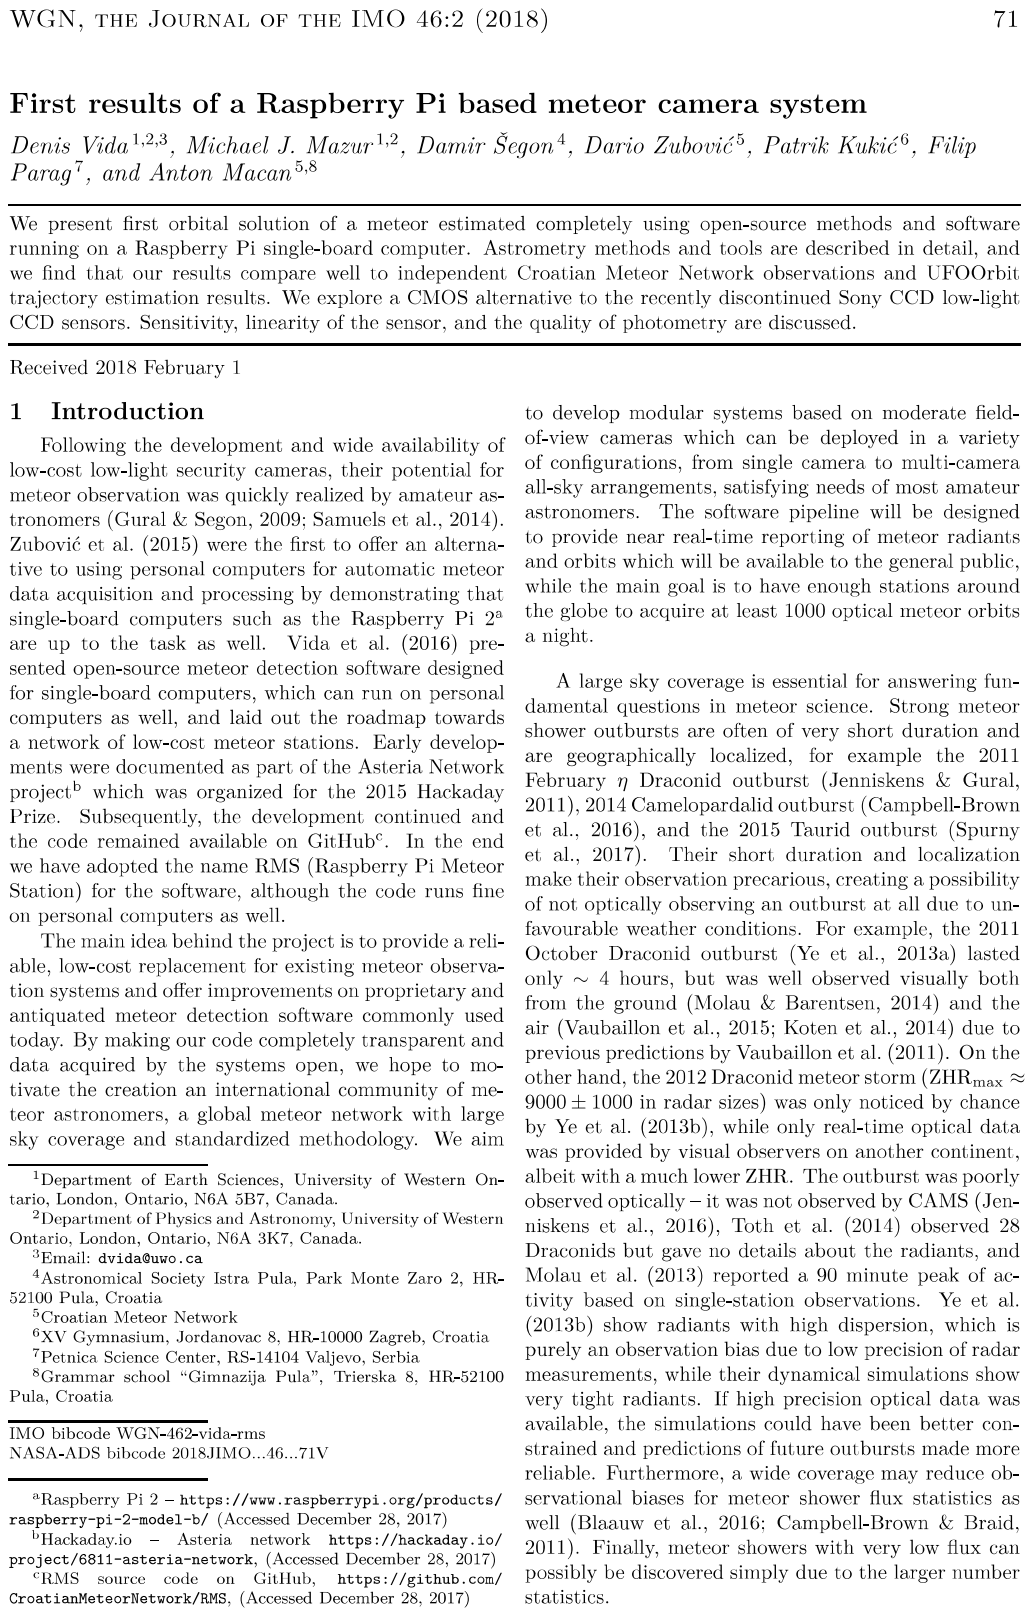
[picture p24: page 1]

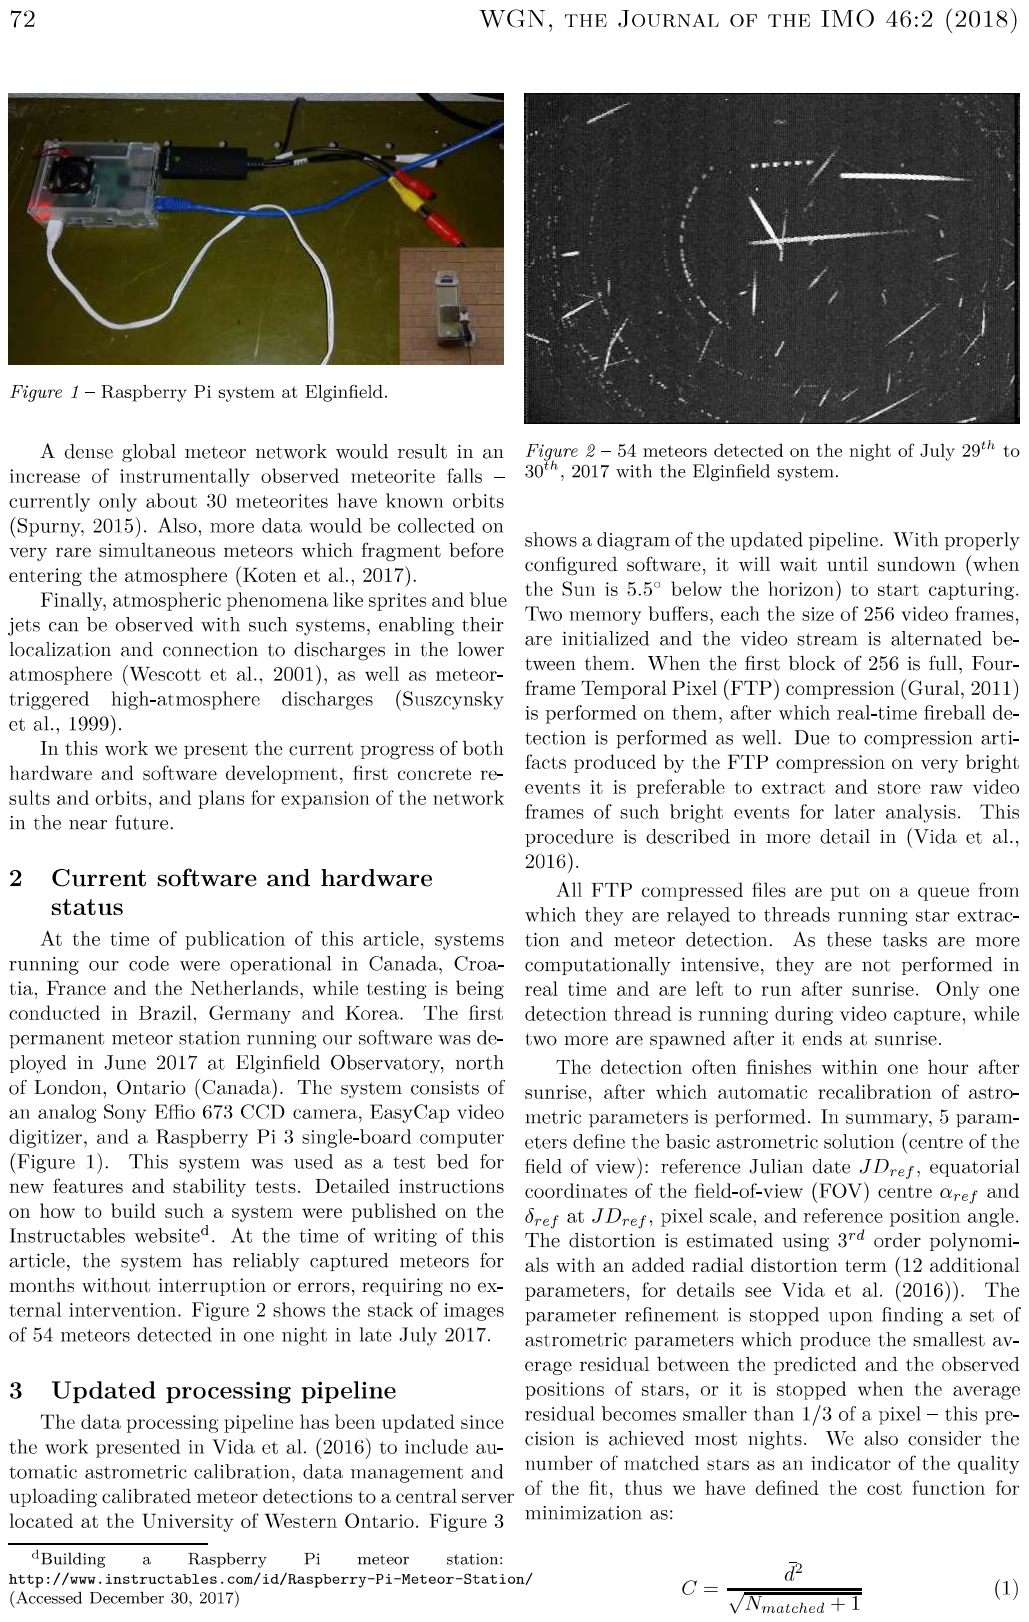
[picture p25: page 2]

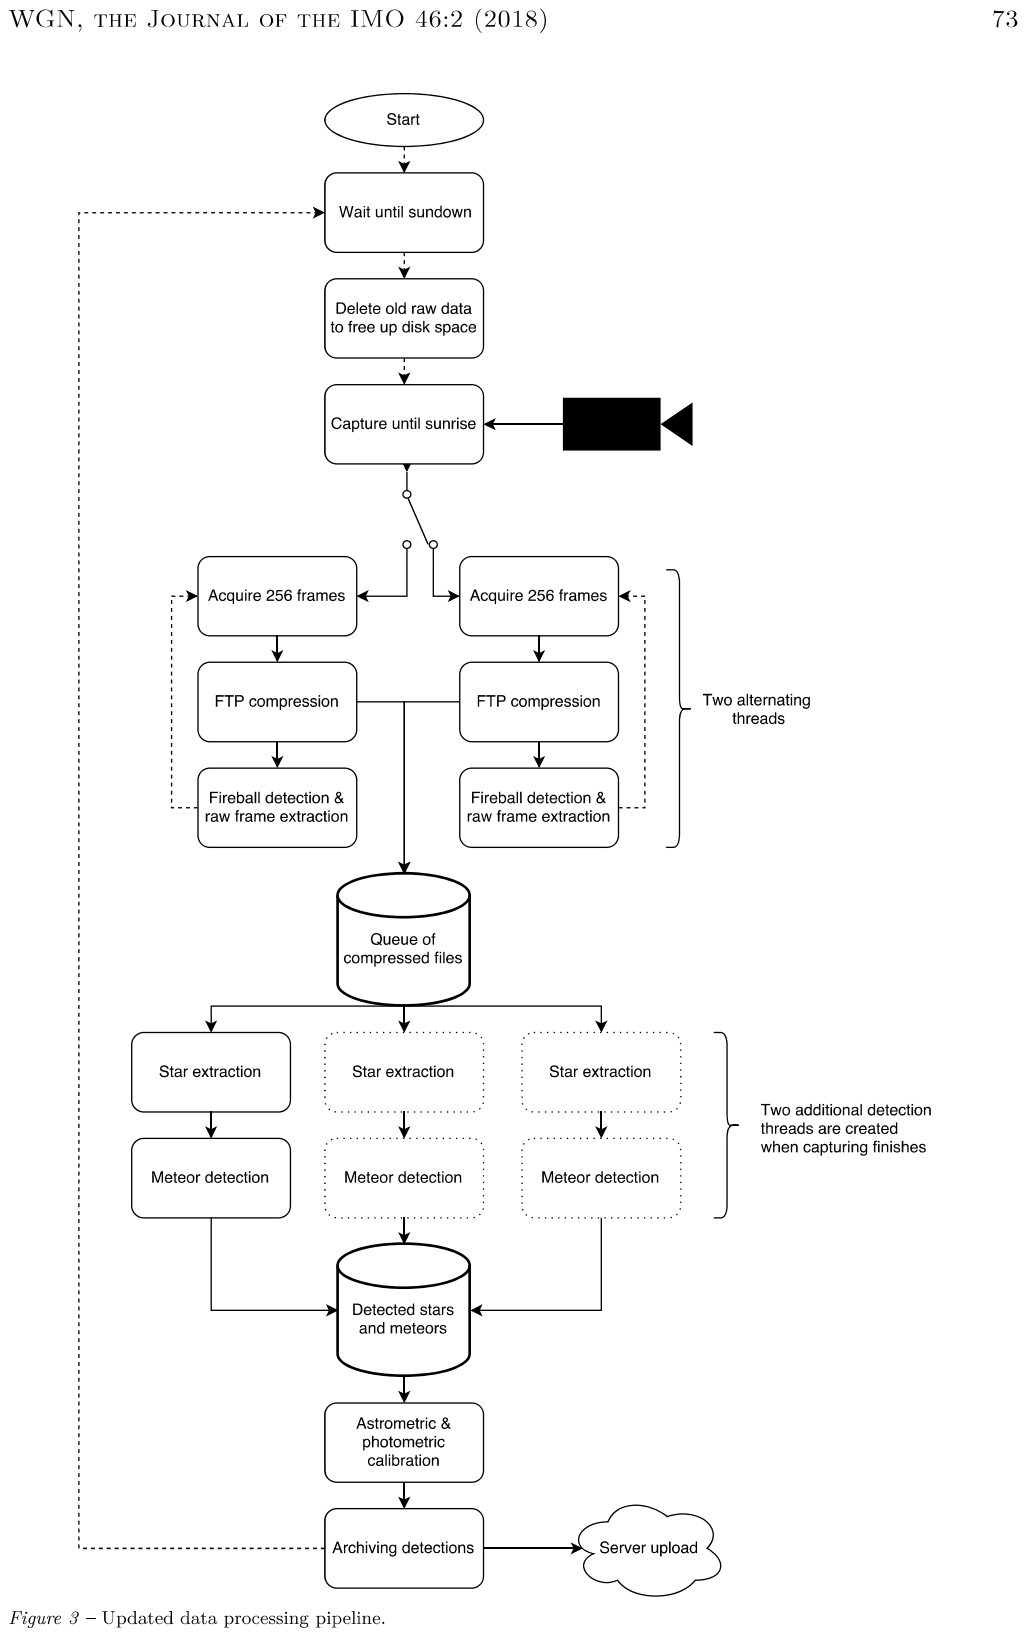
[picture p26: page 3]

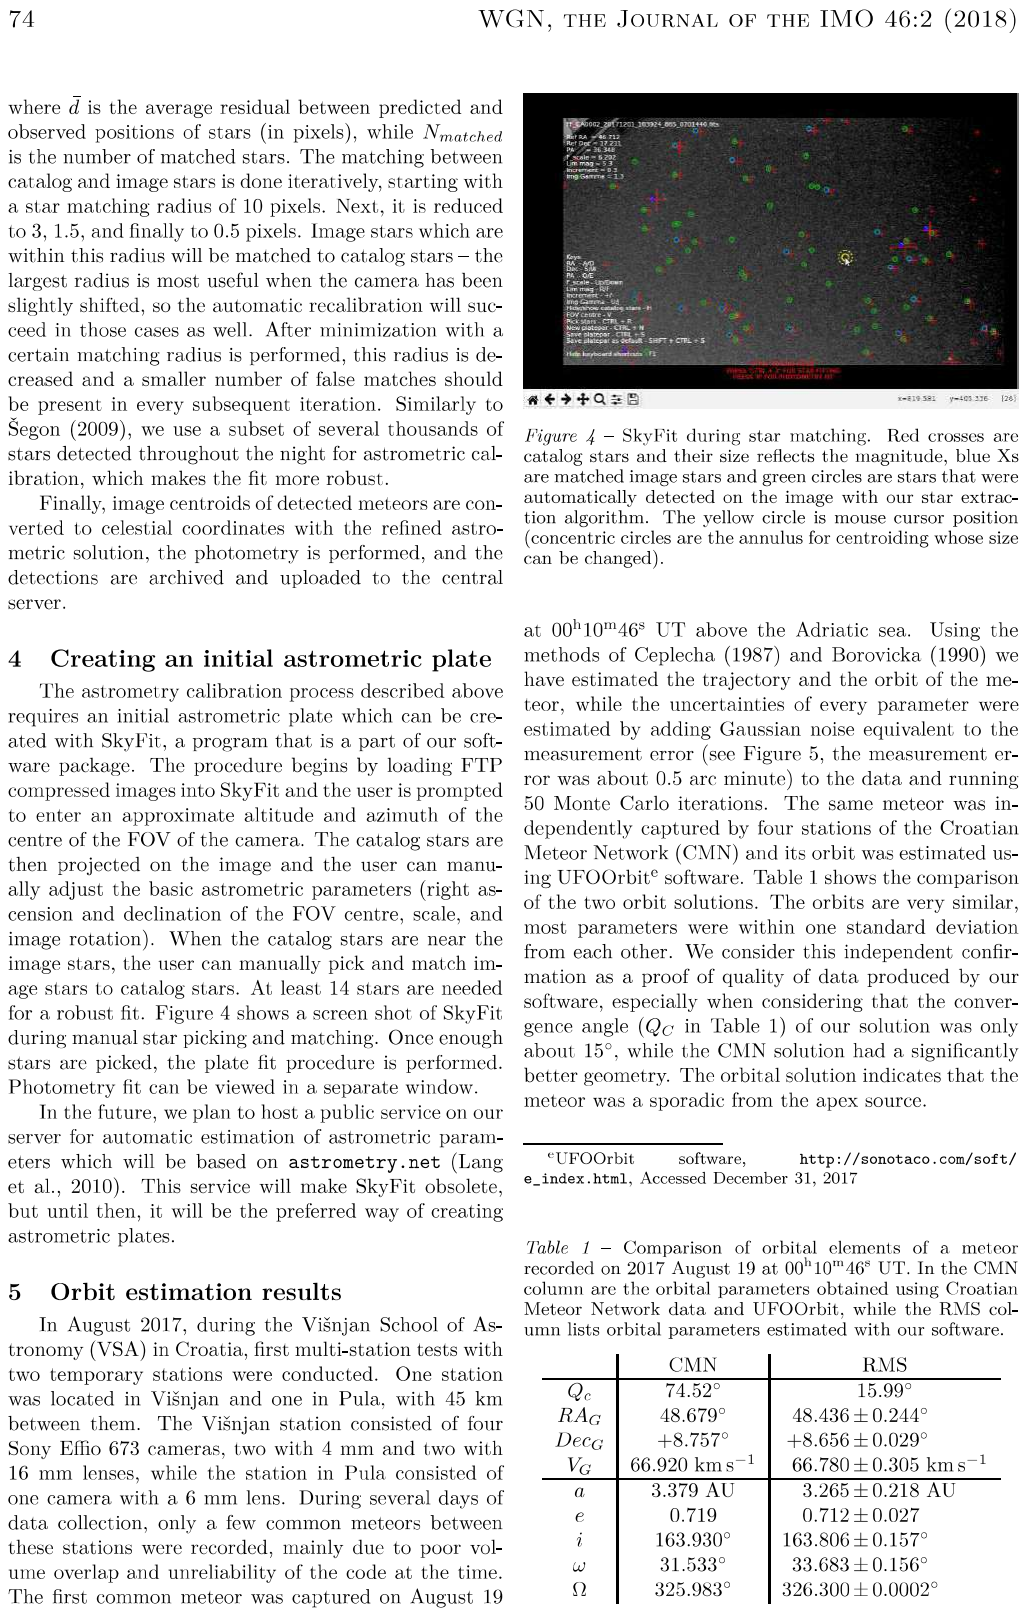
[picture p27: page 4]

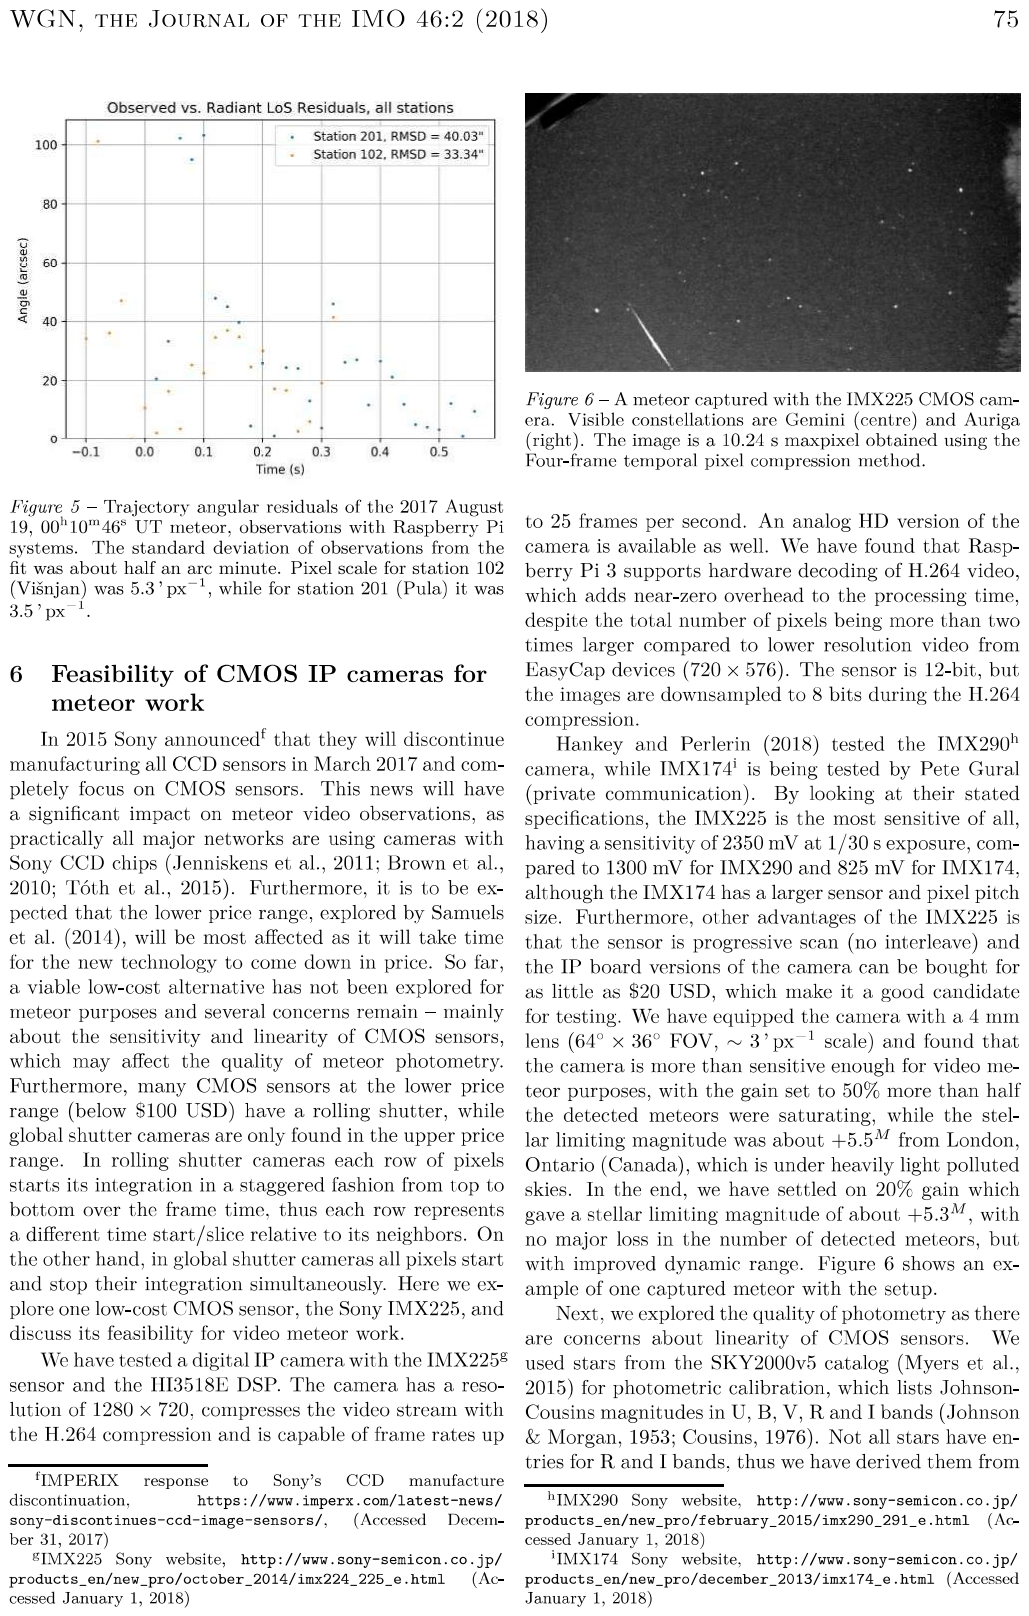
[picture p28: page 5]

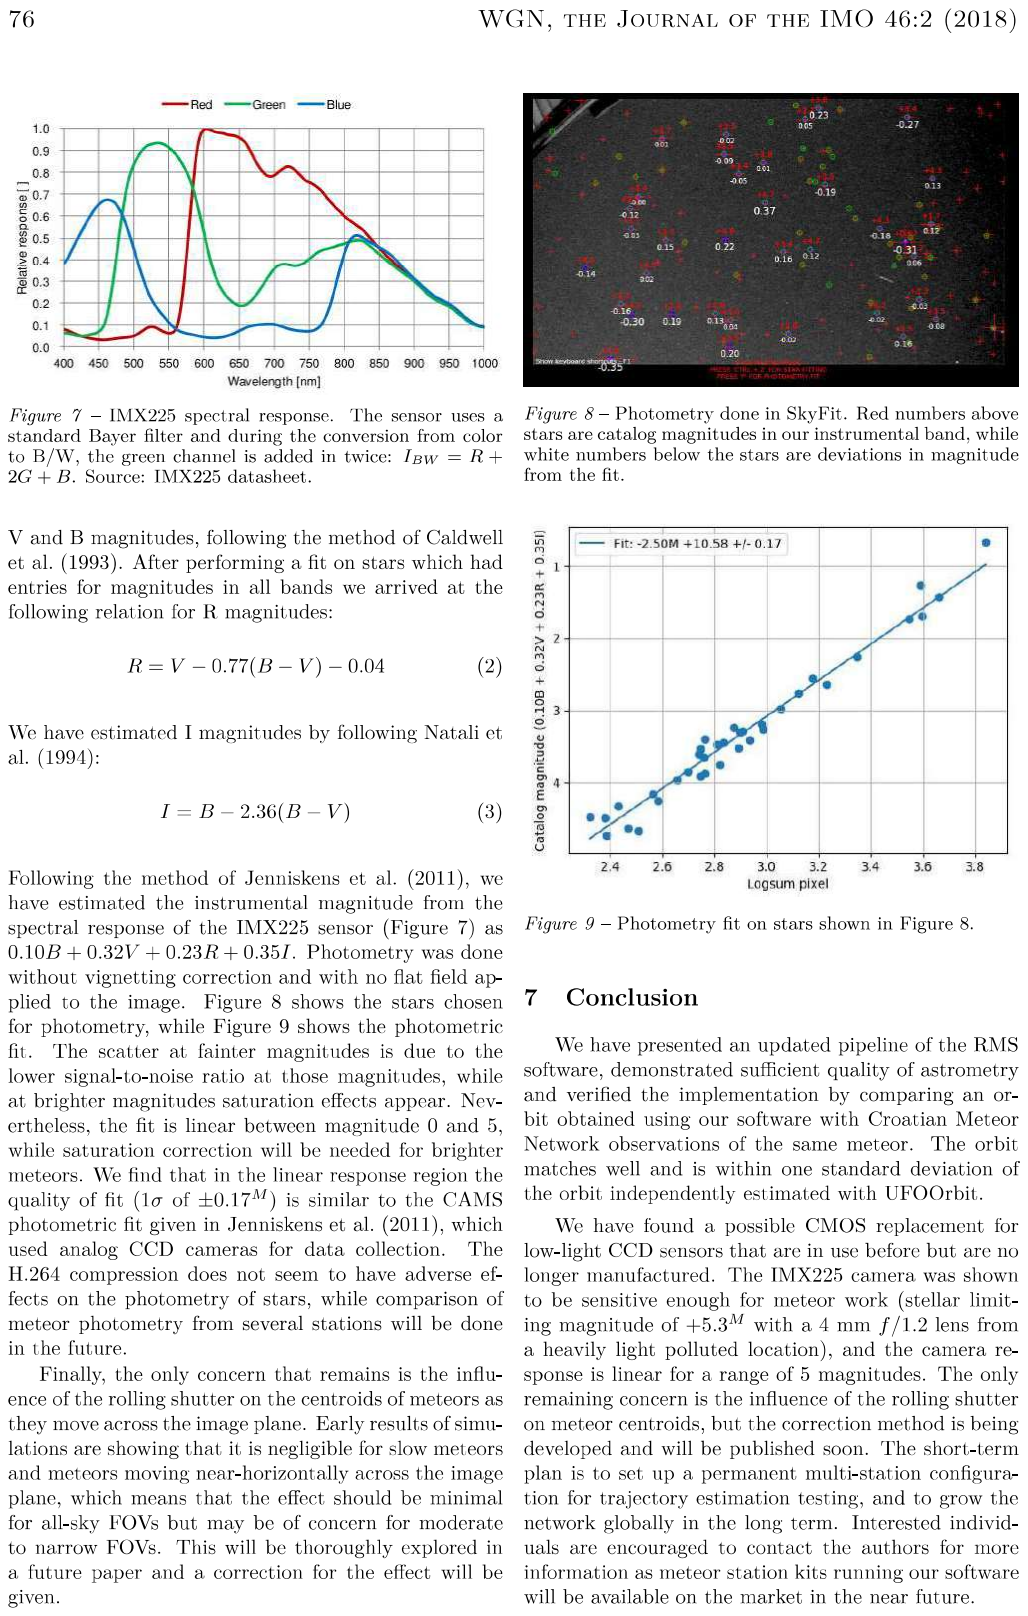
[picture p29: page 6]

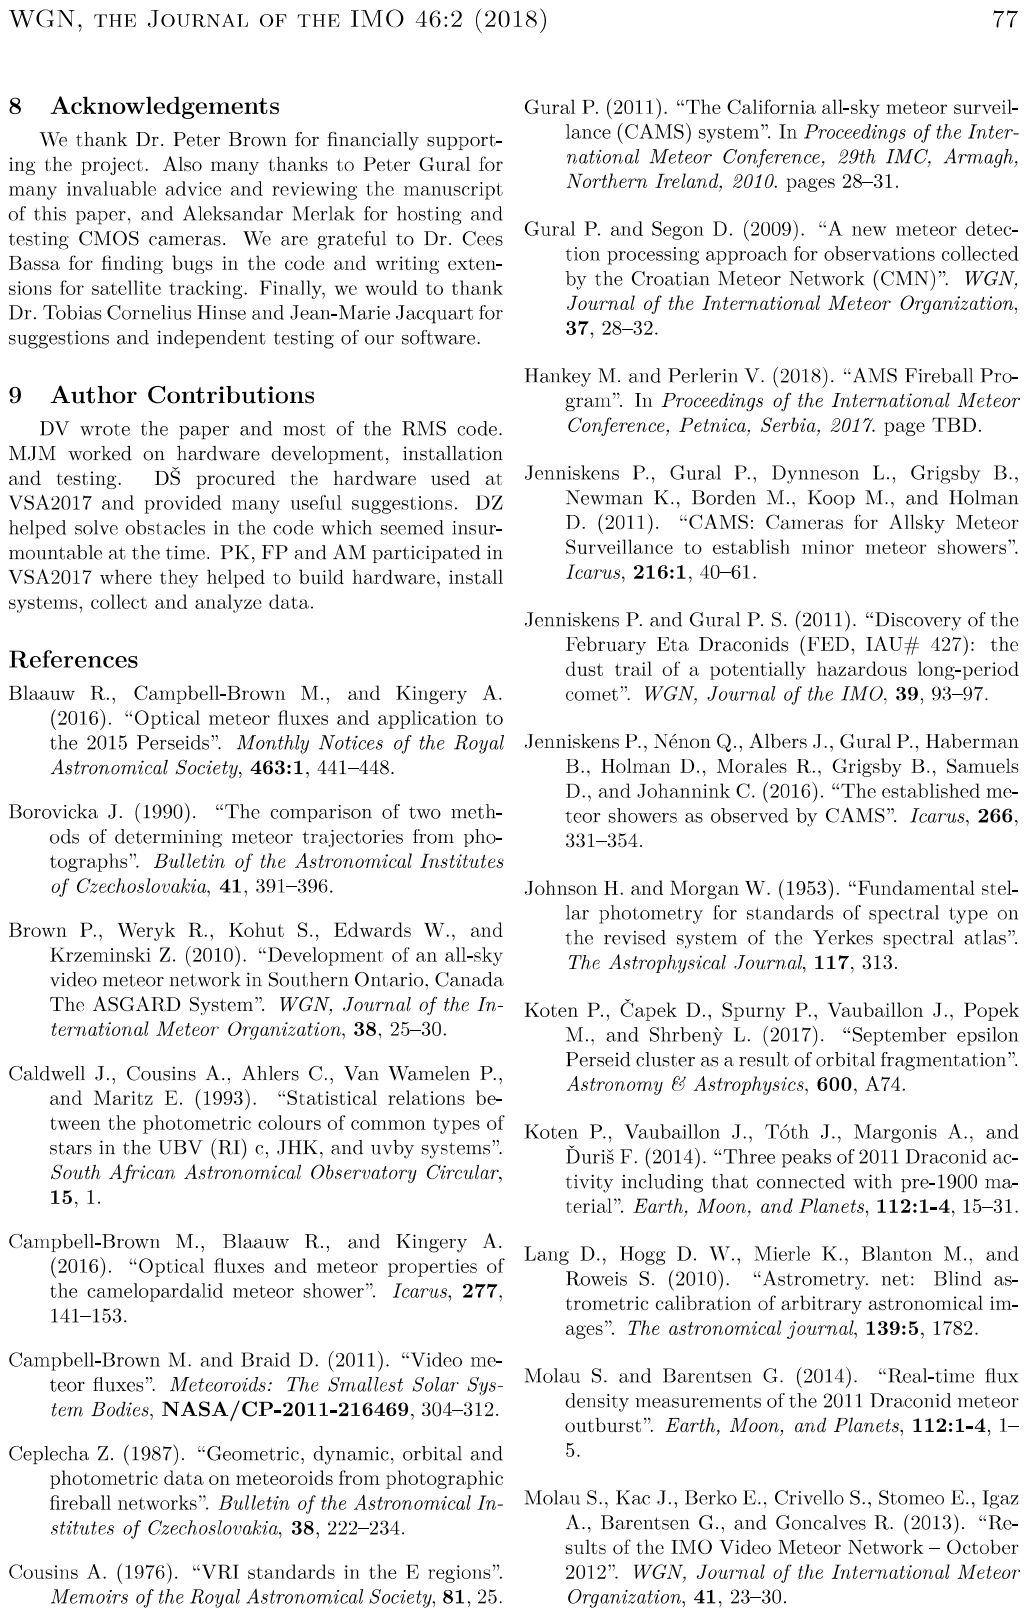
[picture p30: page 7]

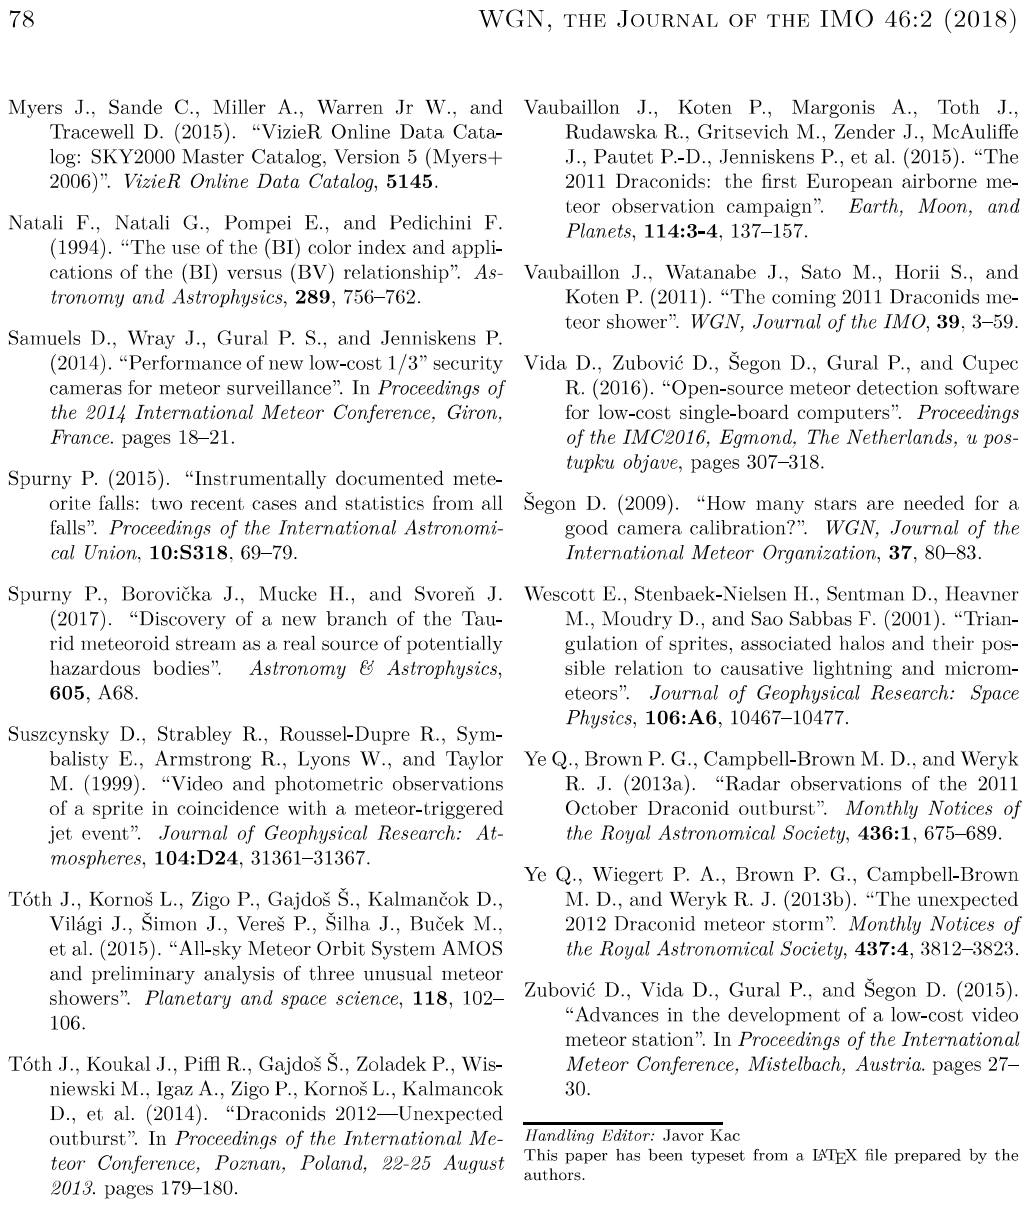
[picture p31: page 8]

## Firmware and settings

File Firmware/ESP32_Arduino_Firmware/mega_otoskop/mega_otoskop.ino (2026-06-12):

/*
 * Otoskop - Arduino Mega 2560 firmware
 * --------------------------------------------------------------------------
 * Gorev: sensorler + motorlar. ESP32-CAM ile UART uzerinden (Serial1)
 * satir-sonlu JSON konusur. ESP WiFi/HTTP/kamera tarafini yonetir; Mega
 * sadece "kas + duyu".
 *
 * Sensorler:
 *   - MPU9250 (I2C, 0x68 + manyetometre AK8963 0x0C):
 *       azimut  = tilt-kompanze manyetometre heading (gercek pusula)
 *       altitude = ivmeolcer pitch
 *       gyro     = heading yumusatma (complementary filter)
 *   - GPS (NEO-6M/M8N, TinyGPSPlus, Serial2): lat/lon/fix
 *
 * Motorlar:
 *   - Azimut (pan): SUREKLI DONUS servosu (180'de durmaz, 360 doner). Konum
 *     acisi yok; komut = hiz. MPU heading'e gore KAPALI DONGU surulur.
 *   - Altitude (tilt): NORMAL KONUM servosu (0..180). Yukari limiti kullanici
 *     belirler ({"cmd":"limits","altMax":..}).
 *   Tum hareketler "300ms'de 1 derece" hizinda yumusak ilerler.
 *
 * Haberlesme (Serial1, 115200, satir-sonlu JSON):
 *   ESP -> Mega komut:
 *     {"cmd":"target","az":135.4,"alt":42.8}
 *     {"cmd":"move","dir":"right","step":"medium"}     dir: left|right|up|down
 *     {"cmd":"correction","daz":-0.8,"dalt":0.5}
 *     {"cmd":"calibrate"}                              gyro/mag kalibrasyonu
 *     {"cmd":"calOffset","daz":12.0,"dalt":-3.0}       yon kalibrasyonu (telefonla)
 *     {"cmd":"limits","altMax":60.0}                   altitude yukari limiti
 *     {"cmd":"track","on":true}
 *   Mega -> ESP telemetri (~10 Hz):
 *     {"az":134.8,"alt":42.1,"taz":135.4,"talt":42.8,"sAz":67.4,"sAlt":42.1,
 *      "gps":true,"lat":41.0,"lon":28.9,"imu":true,"trk":true,"lock":false}
 *
 * Kablolama (Mega):
 *   MPU9250 : VCC 3.3V (veya modul 5V toleransli ise 5V), GND, SDA=20, SCL=21
 *   GPS     : VCC 5V, GND, GPS-TX -> Mega RX2(17), GPS-RX -> Mega TX2(16)
 *   ESP link: Mega TX1(18) -> [GERILIM BOLUCU 5V->3.3V] -> ESP RX
 *             Mega RX1(19) <- ESP TX (3.3V, dogrudan okunur)
 *             ORTAK GND sart!
 *   Servo Az: sinyal -> pin 9   (harici 5V besleme, ortak GND)
 *   Servo Alt: sinyal -> pin 10
 *
 * Gerekli kutuphaneler (Arduino Library Manager):
 *   - TinyGPSPlus   (Mikal Hart)
 *   - ArduinoJson   (Benoit Blanchon, 6.x onerilir)
 *   - Servo         (Arduino built-in)
 */

#include <Wire.h>
#include <Servo.h>
#include <ArduinoJson.h>
#include <TinyGPSPlus.h>
#include <EEPROM.h>
#include <math.h>

// ----------------------------- Ayarlar -------------------------------------
// 1: telemetriyi USB seri monitore de yaz (Mega'nin veri uretip uretmedigini
// dogrulamak icin). Arduino IDE Serial Monitor'u 115200'de ac -> {"az":...}
// satirlari akmali. Hata ayiklama bitince 0 yapabilirsin.
#define DEBUG_USB     1

#define MPU_ADDR      0x68
#define AK8963_ADDR   0x0C
#define GYRO_SENS     131.0   // +-250 dps modunda LSB/dps

#define SERVO_AZ_PIN  9
#define SERVO_ALT_PIN 10

// --------------------------- Servo mimarisi --------------------------------
// AZIMUT (yatay/pan): SUREKLI DONUS servosu (DS5160 sw vb. - 180'de durmaz,
//   360 doner). Konum acisi YOK; komut = HIZ. Bu yuzden hedef azimuta gitmek
//   icin MPU heading'e gore KAPALI DONGU surulur: hedefe gelene kadar yavas
//   dondur, gelince durdur. writeMicroseconds ile sürülür:
//     AZ_STOP_US      -> dur (notr). Servon biraz suruyorsa bunu trim et.
//     +/- AZ_SLEW_US  -> notr'den sapma = donus hizi (kucuk = yavas).
//   Donus yonu ters cikarsa AZ_DIR'i -1 yap.
const int   AZ_STOP_US   = 1500;   // surekli servo notr (dur) puls genisligi
const int   AZ_SLEW_US   = 90;     // notr'den sapma (yavas donus). Buyut=hizlan
const int   AZ_DIR       = 1;      // donus yonu (+1 / -1). Ters donerse degistir
const float AZ_TOLERANCE_DEG = 1.0;  // bu kadar yakinsa azimut servosunu durdur

// ALTITUDE (dikey/tilt): NORMAL KONUM servosu (0..180 yazilir). Asagi yonun
//   onemi yok; yukari limiti KULLANICI belirler (uygulamadaki ayar sayfasi ->
//   {"cmd":"limits","altMax":..}). Servo acisi = altitude * ALT_SERVO_SCALE.
const float ALT_SERVO_SCALE  = 1.0;  // mekanik orana gore (1:1 ise 1.0)
const float ALT_MIN_DEG      = 0.0;

// Hareket adimlama: hedefe "300ms'de 1 derece" hizinda yumusak yaklasilir.
const unsigned long STEP_INTERVAL_MS = 300;
const float         STEP_DEG         = 1.0;

const float LOCK_TOLERANCE_DEG = 2.0;  // hedefe bu kadar yakinsa kilit

// --------------------------- Kalibrasyon / limit (kalici, EEPROM) ----------
// Yon kalibrasyonu: telefon (gercek referans) ile MPU okumasi arasindaki fark.
//   azReal = normalize(hamHeading + azOffset);  altReal = hamAlt + altOffset
// Uygulama kalibrasyonda artimsal delta gonderir: {"cmd":"calOffset","daz":..,"dalt":..}
float azOffset  = 0.0;
float altOffset = 0.0;
// Altitude yukari limiti (derece). Uygulamadaki ayar sayfasindan degistirilir.
float altMaxLimit = 90.0;

#define EEPROM_MAGIC 0x4F   // 'O' - EEPROM'da gecerli config var mi?

// Manyetometre hard-iron offset (kalibrasyonla bul, buraya yaz).
// uT cinsinden; varsayilan 0 -> kalibre etmeden de calisir ama sapma olur.
float magOffX = 0.0, magOffY = 0.0, magOffZ = 0.0;
// Yerel manyetik sapma (declination), Istanbul ~ +6 derece. Kendi konumunu gir.
const float MAG_DECLINATION_DEG = 6.0;

// ----------------------------- Durum ---------------------------------------
TinyGPSPlus gps;
Servo servoAz;
Servo servoAlt;

float yaw = 0.0;          // gyro entegre heading (manyetometre ile karisir)
float gzBias = 0.0;
unsigned long lastMicros = 0;

float heading = 0.0;      // HAM azimut (derece, 0..360) - fuzyon cikisi (yaw)
float altitude = 0.0;     // HAM yukseklik acisi (derece) - pitch'ten
float rollDeg = 0.0;      // x ekseni egimi (derece) - debug
float pitchDeg = 0.0;     // y ekseni egimi (derece, ham) - debug

// Kalibrasyon offset'i uygulanmis GERCEK acilar (kapali dongu + telemetri bunu kullanir)
float azReal = 0.0;
float altReal = 0.0;

float targetAz = 0.0;
float targetAlt = 0.0;
bool  haveTarget = false;
bool  tracking = false;
bool  targetLocked = false;

// Adimlanan ara hedef (300ms'de 1 derece ilerler). Servolar buna gore surulur.
float azCmd = 0.0;
float altCmd = 0.0;
unsigned long lastStepMs = 0;

float servoAzPos = 90.0;   // telemetri: azimut komut acisi (azCmd)
float servoAltPos = 0.0;   // telemetri: altitude servo acisi

bool imuOk = false;

// AK8963 hassasiyet duzeltme faktorleri (fabrika ASA)
float magAdjX = 1.0, magAdjY = 1.0, magAdjZ = 1.0;

unsigned long lastTelemetry = 0;
const unsigned long TELEMETRY_INTERVAL_MS = 100;  // 10 Hz

char rxBuf[160];
uint8_t rxLen = 0;

// ----------------------------- I2C yardimcilari ----------------------------
void writeReg(uint8_t addr, uint8_t reg, uint8_t val) {
  Wire.beginTransmission(addr);
  Wire.write(reg);
  Wire.write(val);
  Wire.endTransmission();
}

uint8_t readReg(uint8_t addr, uint8_t reg) {
  Wire.beginTransmission(addr);
  Wire.write(reg);
  Wire.endTransmission(false);
  Wire.requestFrom((int)addr, 1);
  return Wire.available() ? Wire.read() : 0;
}

bool readBytes(uint8_t addr, uint8_t reg, uint8_t n, uint8_t* buf) {
  Wire.beginTransmission(addr);
  Wire.write(reg);
  if (Wire.endTransmission(false) != 0) return false;
  if (Wire.requestFrom((int)addr, (int)n) != n) return false;
  for (uint8_t i = 0; i < n; i++) buf[i] = Wire.read();
  return true;
}

// --------------------------- MPU9250 + AK8963 ------------------------------
bool mpuInit() {
  uint8_t who = readReg(MPU_ADDR, 0x75);   // WHO_AM_I (0x71 = 9250, 0x73 = 9255)
  writeReg(MPU_ADDR, 0x6B, 0x00);          // uyandir
  delay(10);
  writeReg(MPU_ADDR, 0x1B, 0x00);          // gyro +-250 dps
  writeReg(MPU_ADDR, 0x1C, 0x00);          // accel +-2g
  // I2C bypass ac -> AK8963'e dogrudan erisim
  writeReg(MPU_ADDR, 0x37, 0x02);
  delay(10);

  // AK8963 fabrika ASA degerlerini oku
  writeReg(AK8963_ADDR, 0x0A, 0x00);       // power down
  delay(10);
  writeReg(AK8963_ADDR, 0x0A, 0x0F);       // fuse ROM access
  delay(10);
  uint8_t asa[3];
  readBytes(AK8963_ADDR, 0x10, 3, asa);
  magAdjX = (asa[0] - 128) / 256.0 + 1.0;
  magAdjY = (asa[1] - 128) / 256.0 + 1.0;
  magAdjZ = (asa[2] - 128) / 256.0 + 1.0;
  writeReg(AK8963_ADDR, 0x0A, 0x00);
  delay(10);
  writeReg(AK8963_ADDR, 0x0A, 0x16);       // 16-bit, 100Hz continuous
  delay(10);

  return (who == 0x71 || who == 0x73 || who != 0x00);
}

bool readAccelGyro(float &ax, float &ay, float &az,
                   float &gx, float &gy, float &gz) {
  uint8_t b[14];
  if (!readBytes(MPU_ADDR, 0x3B, 14, b)) return false;
  int16_t rax = (b[0] << 8) | b[1];
  int16_t ray = (b[2] << 8) | b[3];
  int16_t raz = (b[4] << 8) | b[5];
  int16_t rgx = (b[8] << 8) | b[9];
  int16_t rgy = (b[10] << 8) | b[11];
  int16_t rgz = (b[12] << 8) | b[13];
  if (rax == -32768 || ray == -32768) return false;
  ax = rax; ay = ray; az = raz;
  gx = rgx; gy = rgy; gz = rgz;
  return true;
}

// Manyetometre okuma (uT). AK8963 ekseni MPU eksenine gore farkli:
// mx<-y, my<-x, mz<--z (datasheet hizalama).
bool readMag(float &mx, float &my, float &mz) {
  if (!(readReg(AK8963_ADDR, 0x02) & 0x01)) return false;  // DRDY
  uint8_t b[7];
  if (!readBytes(AK8963_ADDR, 0x03, 7, b)) return false;
  if (b[6] & 0x08) return false;                           // HOFL overflow
  int16_t rx = (b[1] << 8) | b[0];
  int16_t ry = (b[3] << 8) | b[2];
  int16_t rz = (b[5] << 8) | b[4];
  const float scale = 4912.0 / 32760.0;  // uT/LSB (16-bit)
  float mxr = ry * scale * magAdjY;
  float myr = rx * scale * magAdjX;
  float mzr = -rz * scale * magAdjZ;
  mx = mxr - magOffX;
  my = myr - magOffY;
  mz = mzr - magOffZ;
  return true;
}

void calibrateGyro() {
  const int N = 400;
  float ax, ay, az, gx, gy, gz;
  long n = 0; double sum = 0;
  for (int i = 0; i < N; i++) {
    if (readAccelGyro(ax, ay, az, gx, gy, gz)) { sum += gz; n++; }
    delay(2);
  }
  if (n > 0) gzBias = sum / n;
}

// 5 sn boyunca sensoru her yone cevir -> hard-iron offset (min/max ortalama).
void calibrateMag() {
  float mx, my, mz;
  float mnx = 1e6, mxx = -1e6, mny = 1e6, mxy = -1e6, mnz = 1e6, mxz = -1e6;
  unsigned long t0 = millis();
  while (millis() - t0 < 8000) {
    if (readMag(mx, my, mz)) {
      // okurken offset cikariyoruz; ham degeri geri ekleyip min/max bul
      float rx = mx + magOffX, ry = my + magOffY, rz = mz + magOffZ;
      mnx = min(mnx, rx); mxx = max(mxx, rx);
      mny = min(mny, ry); mxy = max(mxy, ry);
      mnz = min(mnz, rz); mxz = max(mxz, rz);
    }
    delay(10);
  }
  magOffX = (mxx + mnx) / 2.0;
  magOffY = (mxy + mny) / 2.0;
  magOffZ = (mxz + mnz) / 2.0;
}

// --------------------------- Servo surme -----------------------------------
// Iki azimut arasi en kisa fark (-180..180).
float shortestAngle(float from, float to) {
  float d = fmod(to - from, 360.0);
  if (d > 180.0)  d -= 360.0;
  if (d < -180.0) d += 360.0;
  return d;
}

float normAz(float a) { a = fmod(a, 360.0); if (a < 0) a += 360.0; return a; }

// 300ms'de bir ara hedefi (azCmd/altCmd) 1 derece nihai hedefe yaklastir.
// Boylece tum hareketler "300ms'de 1 derece" hizinda yumusak ilerler.
void updateStepTargets() {
  if (millis() - lastStepMs < STEP_INTERVAL_MS) return;
  lastStepMs = millis();

  if (!haveTarget) return;   // hedef yokken servolar yerinde kalir

  // Azimut: en kisa yonden 1 derece
  float dAz = shortestAngle(azCmd, targetAz);
  if (fabs(dAz) <= STEP_DEG) azCmd = targetAz;
  else azCmd = normAz(azCmd + (dAz > 0 ? STEP_DEG : -STEP_DEG));

  // Altitude: 1 derece, kullanici limitine kadar
  float tAlt = constrain(targetAlt, ALT_MIN_DEG, altMaxLimit);
  float dAlt = tAlt - altCmd;
  if (fabs(dAlt) <= STEP_DEG) altCmd = tAlt;
  else altCmd += (dAlt > 0 ? STEP_DEG : -STEP_DEG);
  altCmd = constrain(altCmd, ALT_MIN_DEG, altMaxLimit);
}

void driveServos() {
  // --- AZIMUT: surekli donus servosu, MPU heading'e gore kapali dongu ---
  float errAz = shortestAngle(azReal, azCmd);   // azReal -> azCmd farki
  if (haveTarget && fabs(errAz) > AZ_TOLERANCE_DEG) {
    int dir = (errAz > 0) ? 1 : -1;
    servoAz.writeMicroseconds(AZ_STOP_US + AZ_DIR * dir * AZ_SLEW_US);
  } else {
    servoAz.writeMicroseconds(AZ_STOP_US);      // dur (notr)
  }
  servoAzPos = azCmd;                            // telemetri (komut azimutu)

  // --- ALTITUDE: normal konum servosu (kullanici limitiyle) ---
  float servoAngle = altCmd * ALT_SERVO_SCALE;
  servoAngle = constrain(servoAngle, 0.0, 180.0);
  servoAlt.write((int)round(servoAngle));
  servoAltPos = servoAngle;

  // --- Hedef kilidi ---
  // Azimut kapali dongu: GERCEK heading hedefe yakin mi?
  // Altitude acik dongu (konum servosu): komut nihai hedefe ulasti mi?
  if (haveTarget) {
    float lockAz = fabs(shortestAngle(azReal, targetAz));
    float lockAlt = fabs(constrain(targetAlt, ALT_MIN_DEG, altMaxLimit) - altCmd);
    targetLocked = (lockAz < LOCK_TOLERANCE_DEG && lockAlt < LOCK_TOLERANCE_DEG);
  }
}

// --------------------------- EEPROM (kalici config) ------------------------
void saveConfig() {
  EEPROM.update(0, EEPROM_MAGIC);
  EEPROM.put(1, azOffset);
  EEPROM.put(1 + sizeof(float), altOffset);
  EEPROM.put(1 + 2 * sizeof(float), altMaxLimit);
}

void loadConfig() {
  if (EEPROM.read(0) != EEPROM_MAGIC) return;   // hic kaydedilmemis -> varsayilan
  EEPROM.get(1, azOffset);
  EEPROM.get(1 + sizeof(float), altOffset);
  EEPROM.get(1 + 2 * sizeof(float), altMaxLimit);
  if (isnan(azOffset)) azOffset = 0.0;
  if (isnan(altOffset)) altOffset = 0.0;
  if (isnan(altMaxLimit) || altMaxLimit <= 0) altMaxLimit = 90.0;
}

// --------------------------- Komut isleme ----------------------------------
void handleCommand(const char* line) {
#if DEBUG_USB
  // ESP'den gelen ham komutu USB seri monitore yansit. Buton/kalibre/hedef
  // basildiginda burada gorunuyorsa ESP->Mega yonu (GPIO15 -> Mega RX1/pin19)
  // calisiyor demektir. Hic gorunmuyorsa o kablo/GND yok.
  Serial.print(F("[CMD] "));
  Serial.println(line);
#endif
  StaticJsonDocument<200> doc;
  DeserializationError err = deserializeJson(doc, line);
  if (err) {
#if DEBUG_USB
    Serial.println(F("[CMD] JSON parse HATA"));
#endif
    return;
  }
  const char* cmd = doc["cmd"] | "";

  if (strcmp(cmd, "target") == 0) {
    targetAz = normAz(doc["az"] | targetAz);
    targetAlt = constrain((float)(doc["alt"] | targetAlt), ALT_MIN_DEG, altMaxLimit);
    azCmd = azReal;   // surekli azimut: ara hedef GERCEK heading'den baslasin
    haveTarget = true;
    tracking = true;
    targetLocked = false;
  } else if (strcmp(cmd, "correction") == 0) {
    targetAz = normAz(targetAz + (float)(doc["daz"] | 0.0));
    targetAlt = constrain(targetAlt + (float)(doc["dalt"] | 0.0), ALT_MIN_DEG, altMaxLimit);
    haveTarget = true;
  } else if (strcmp(cmd, "move") == 0) {
    const char* dir = doc["dir"] | "";
    const char* step = doc["step"] | "medium";
    float s = 1.0;
    if (strcmp(step, "small") == 0) s = 0.5;
    else if (strcmp(step, "large") == 0) s = 5.0;
    else s = 2.0;
    if (!haveTarget) { targetAz = azReal; targetAlt = altReal; azCmd = azReal; haveTarget = true; }
    if (strcmp(dir, "left") == 0)  targetAz -= s;
    if (strcmp(dir, "right") == 0) targetAz += s;
    if (strcmp(dir, "up") == 0)    targetAlt += s;
    if (strcmp(dir, "down") == 0)  targetAlt -= s;
    targetAz = normAz(targetAz);
    targetAlt = constrain(targetAlt, ALT_MIN_DEG, altMaxLimit);
  } else if (strcmp(cmd, "track") == 0) {
    tracking = doc["on"] | false;
  } else if (strcmp(cmd, "calibrate") == 0) {
    calibrateGyro();
    calibrateMag();
    yaw = heading;
  } else if (strcmp(cmd, "calOffset") == 0) {
    // Yon kalibrasyonu: telefon (gercek) ile MPU farkinin ARTIMSAL eklenmesi.
    azOffset = normAz(azOffset + (float)(doc["daz"] | 0.0));
    altOffset += (float)(doc["dalt"] | 0.0);
    saveConfig();
  } else if (strcmp(cmd, "limits") == 0) {
    // Altitude yukari limiti (kullanici belirler). Hedefi de hemen kis.
    altMaxLimit = constrain((float)(doc["altMax"] | altMaxLimit), 1.0, 180.0);
    targetAlt = constrain(targetAlt, ALT_MIN_DEG, altMaxLimit);
    saveConfig();
  }
}

void pollSerialCommands() {
  while (Serial1.available()) {
    char c = Serial1.read();
    if (c == '\n' || c == '\r') {
      if (rxLen > 0) { rxBuf[rxLen] = '\0'; handleCommand(rxBuf); rxLen = 0; }
    } else if (rxLen < sizeof(rxBuf) - 1) {
      rxBuf[rxLen++] = c;
    } else {
      rxLen = 0;  // tasma -> sifirla
    }
  }
}

// --------------------------- Telemetri -------------------------------------
void sendTelemetry() {
  StaticJsonDocument<512> doc;
  // az/alt = kalibrasyon offset'i uygulanmis GERCEK acilar (uygulama bunu gosterir)
  doc["az"] = round(azReal * 10) / 10.0;
  doc["alt"] = round(altReal * 10) / 10.0;
  doc["taz"] = round(targetAz * 10) / 10.0;
  doc["talt"] = round(targetAlt * 10) / 10.0;
  doc["sAz"] = round(servoAzPos * 10) / 10.0;
  doc["sAlt"] = round(servoAltPos * 10) / 10.0;
  // Ham yonelim acilari (x/y/z): roll, pitch, yaw. yaw = HAM fuzyon heading.
  doc["roll"] = round(rollDeg * 10) / 10.0;
  doc["pitch"] = round(pitchDeg * 10) / 10.0;
  doc["yaw"] = round(heading * 10) / 10.0;
  // Kalibrasyon/limit durumu (uygulama gosterimi icin)
  doc["azOff"] = round(azOffset * 10) / 10.0;
  doc["altOff"] = round(altOffset * 10) / 10.0;
  doc["altMax"] = round(altMaxLimit * 10) / 10.0;
  doc["gps"] = gps.location.isValid();
  if (gps.location.isValid()) {
    doc["lat"] = gps.location.lat();
    doc["lon"] = gps.location.lng();
  }
  doc["imu"] = imuOk;
  doc["trk"] = tracking;
  doc["lock"] = targetLocked;
  serializeJson(doc, Serial1);
  Serial1.print('\n');
#if DEBUG_USB
  // Ayni telemetriyi USB seri monitore de yansit (Mega debug). Boylece Mega'nin
  // gercekten veri uretip uretmedigini (imu/gps dahil) dogrudan gorursun.
  // ESP'ye giden veri ayni; bu sadece kopyasi.
  serializeJson(doc, Serial);
  Serial.println();
#endif
}

// --------------------------- Sensor fuzyonu --------------------------------
void updateOrientation() {
  float ax, ay, az, gx, gy, gz;
  if (!readAccelGyro(ax, ay, az, gx, gy, gz)) {
    imuOk = false;
    // Otomatik kurtarma: MPU I2C bus'tan dustuyse (gevsek kablo, parazit,
    // acilis sirasi) saniyede bir yeniden baslatmayi dene. Boylece bir kez
    // hata olsa bile baglanti duzelince IMU kendiliginden geri gelir
    // (eskiden imuOk kalici false kaliyordu -> uygulamada surekli kirmizi).
    static unsigned long lastReinit = 0;
    if (millis() - lastReinit > 1000) {
      lastReinit = millis();
      mpuInit();
    }
    return;
  }
  imuOk = true;

  unsigned long now = micros();
  float dt = (now - lastMicros) / 1000000.0;
  lastMicros = now;
  if (dt <= 0 || dt > 0.5) dt = 0.01;

  // Pitch/roll (rad)
  float pitch = atan2(-ax, sqrt(ay * ay + az * az));
  float roll  = atan2(ay, az);
  pitchDeg = pitch * 180.0 / PI;    // ham pitch (debug)
  rollDeg  = roll * 180.0 / PI;     // ham roll  (debug)
  altitude = pitchDeg;              // ham yukseklik (asagi yon serbest)

  // Tilt-kompanze manyetometre heading
  float mx, my, mz;
  static float magHeading = 0.0;
  if (readMag(mx, my, mz)) {
    float xh = mx * cos(pitch) + mz * sin(pitch);
    float yh = mx * sin(roll) * sin(pitch) + my * cos(roll)
             - mz * sin(roll) * cos(pitch);
    float h = atan2(-yh, xh) * 180.0 / PI + MAG_DECLINATION_DEG;
    if (h < 0) h += 360.0;
    magHeading = h;
  }

  // Gyro Z entegrasyonu + complementary filter (drift'i mag ile duzelt)
  float gzDps = (gz - gzBias) / GYRO_SENS;
  yaw += gzDps * dt;
  float diff = magHeading - yaw;
  while (diff > 180) diff -= 360;
  while (diff < -180) diff += 360;
  yaw += diff * 0.02;   // %2 manyetometre duzeltmesi/loop
  heading = fmod(yaw, 360.0); if (heading < 0) heading += 360.0;

  // Kalibrasyon offset'ini uygula -> GERCEK (dunya) acilari.
  azReal = normAz(heading + azOffset);
  altReal = altitude + altOffset;
}

// --------------------------- Setup / Loop ----------------------------------
void setup() {
  Serial.begin(115200);          // USB debug
  Serial1.begin(115200);         // ESP link
  Serial2.begin(9600);           // GPS (NEO-6M varsayilan 9600)
  Wire.begin();
  // 100 kHz: dupont/uzun kablolarda 400 kHz'e gore cok daha guvenilir.
  // MPU9250'den okuma araliklarinda hata (imuOk=false) yasayanlarin en sik
  // cozumu budur; 10 Hz telemetri icin hiz fazlasiyla yeterli.
  Wire.setClock(100000);

  loadConfig();   // kalici azOffset/altOffset/altMaxLimit

  // Surekli servoda 544..2400us tam araligi kullanabilmek icin min/max ver.
  servoAz.attach(SERVO_AZ_PIN, 500, 2500);
  servoAlt.attach(SERVO_ALT_PIN);
  servoAz.writeMicroseconds(AZ_STOP_US);   // azimut: dur (notr)
  servoAlt.write(0);                       // altitude: en alt

  imuOk = mpuInit();
  delay(50);
  calibrateGyro();
  lastMicros = micros();
  lastStepMs = millis();
  Serial.println(imuOk ? F("MPU9250 hazir") : F("MPU9250 bulunamadi"));
}

void loop() {
#if DEBUG_USB
  // Kalp atisi: loop'un en BASINDA, her saniye yaz. Boylece:
  //  - hic "[LOOP]" gormuyorsan -> ya yeni kod yuklenmedi ya da loop hic
  //    calismiyor (setup'ta takildi).
  //  - "[LOOP]" surekli artiyorsa -> loop donuyor; asagida telemetri de
  //    akmali. "[LOOP]" bir kez cikip duruyorsa -> loop govdesi takiliyor
  //    (updateOrientation/I2C). imuOk degerini de gosterir.
  static unsigned long lastBeat = 0;
  static unsigned long loopCount = 0;
  loopCount++;
  if (millis() - lastBeat > 1000) {
    lastBeat = millis();
    Serial.print(F("[LOOP] n="));
    Serial.print(loopCount);
    Serial.print(F(" imuOk="));
    Serial.println(imuOk ? 1 : 0);
  }
#endif

  // GPS beslemesi
  while (Serial2.available()) gps.encode(Serial2.read());

  updateOrientation();
  pollSerialCommands();
  updateStepTargets();   // 300ms'de 1 derece ara hedef ilerlemesi
  driveServos();

  if (millis() - lastTelemetry >= TELEMETRY_INTERVAL_MS) {
    lastTelemetry = millis();
    sendTelemetry();
  }
}

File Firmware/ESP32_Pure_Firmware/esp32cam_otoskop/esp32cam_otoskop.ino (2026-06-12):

/*
 * Otoskop - ESP32-CAM (AI-Thinker) firmware
 * --------------------------------------------------------------------------
 * Gorev: WiFi kapisi + kamera + Mega koprusu.
 *   - WiFi AP (SSID "Otoskop", IP 192.168.4.1) -> Android app baglanir.
 *   - HTTP API: app'in bekledigi tum endpoint'ler.
 *   - Kamera: /camera (tek JPEG), /stream (MJPEG canli).
 *   - Mega ile UART2 (Serial2) uzerinden satir-sonlu JSON konusur:
 *       komutlari Mega'ya iletir, telemetriyi Mega'dan okuyup /status verir.
 *
 * HTTP API (port 80):
 *   GET  /status      -> TelescopeStatus JSON (app polling)
 *   GET  /camera      -> image/jpeg (tek kare snapshot)
 *   GET  /stream      -> multipart/x-mixed-replace MJPEG
 *   GET  /gps         -> {"lat":..,"lon":..,"fix":bool}
 *   POST /target      -> {"name":..,"azimuth":..,"altitude":..}
 *   POST /move        -> {"direction":"left|right|up|down","step":"small|medium|large"}
 *   POST /correction  -> {"azimuthCorrection":..,"altitudeCorrection":..}
 *   POST /calibrate                                   gyro/mag kalibrasyonu
 *   POST /caloffset   -> {"azimuthOffset":..,"altitudeOffset":..}  yon kalibrasyonu
 *   POST /limits      -> {"altMax":..}                altitude yukari limiti
 *   GET  /ota/check   -> bulut OTA'yi hemen tetikler (yeni surum varsa gunceller)
 *
 * Mega link kablolama:
 *   ESP RX2 = GPIO13  <- Mega TX1(18) [GERILIM BOLUCU 5V->3.3V uzerinden]
 *   ESP TX2 = GPIO15  -> Mega RX1(19)
 *   ORTAK GND. NOT: Kart programlanirken Mega baglantisini sok (UART karismasin).
 *
 * Gerekli: Arduino-ESP32 board paketi (esp32 by Espressif), ArduinoJson.
 * Kart secimi: "AI Thinker ESP32-CAM". PSRAM acik.
 *
 * AG / BULMA:
 *   - ESP, WIFI_NETS'teki aglardan (telefon hotspot + ev wifi) hangisi varsa
 *     ona baglanir (WiFiMulti). Ayni anda "Otoskop" AP'si de aciktir.
 *   - mDNS ile kendini "otoskop.local" olarak yayinlar; Android app IP yerine
 *     bunu kullanip cihazi otomatik bulur (DHCP IP degisse de calisir).
 *
 * KABLOSUZ KOD YUKLEME - IKI YOL:
 *
 * 1) AYNI AG (ArduinoOTA): bilgisayar ESP ile ayni agdayken Arduino IDE
 *    Tools > Port'ta "otoskop at <IP>" cikar, normal Upload.
 *
 * 2) INTERNET UZERINDEN / BULUT (HTTP OTA pull) -- masaustu ile ESP farkli
 *    aglardayken (orn. ESP telefon hotspot'unda, sen kablolu internette):
 *      - Belli araliklarla OTA_VERSION_URL'deki version.json'a bakar:
 *          {"version": 2, "url": "https://.../firmware.bin"}
 *      - version > FW_VERSION ise firmware.bin'i indirip kendini gunceller.
 *      - Sen masaustunde .bin'i derleyip GitHub'a push edersin (ota/ klasoru +
 *        version.json'daki sayiyi artir). Yardimci: tools/release.ps1
 *      - GET /ota/check  -> guncellemeyi hemen tetikler (beklemeden).
 *
 * NOT: Her iki yol da OTA'li partition semasi ister
 *   (Tools > Partition Scheme > "Minimal SPIFFS (1.9MB APP with OTA)").
 *   Ilk yukleme bir kez kabloyla yapilmalidir; sonrasi kablosuz.
 */

#include "esp_camera.h"
#include <WiFi.h>
#include <WiFiMulti.h>          // birden fazla agdan birine otomatik baglanma
#include <ESPmDNS.h>            // otoskop.local -> app otomatik bulsun
#include <WebServer.h>
#include <ArduinoJson.h>
#include <ArduinoOTA.h>
#include <HTTPClient.h>
#include <WiFiClientSecure.h>
#include <HTTPUpdate.h>
#include <esp_ota_ops.h>
#include <esp_partition.h>
#include "soc/soc.h"             // brownout dedektorunu kapatmak icin
#include "soc/rtc_cntl_reg.h"
#include "lwip/sockets.h"        // SO_SNDTIMEO: takilan stream yazimini bosa cikar

// ----------------------- AI-Thinker ESP32-CAM pinleri ----------------------
#define PWDN_GPIO_NUM     32
#define RESET_GPIO_NUM    -1
#define XCLK_GPIO_NUM      0
#define SIOD_GPIO_NUM     26
#define SIOC_GPIO_NUM     27
#define Y9_GPIO_NUM       35
#define Y8_GPIO_NUM       34
#define Y7_GPIO_NUM       39
#define Y6_GPIO_NUM       36
#define Y5_GPIO_NUM       21
#define Y4_GPIO_NUM       19
#define Y3_GPIO_NUM       18
#define Y2_GPIO_NUM        5
#define VSYNC_GPIO_NUM    25
#define HREF_GPIO_NUM     23
#define PCLK_GPIO_NUM     22

// Mega link UART2 pinleri
#define MEGA_RX_PIN 13   // ESP girisi  (Mega TX'ten)
#define MEGA_TX_PIN 15   // ESP cikisi  (Mega RX'e)

// AI-Thinker ESP32-CAM uzerindeki parlak beyaz flash LED. OTA indirilirken
// yanip soner (gorsel gosterge), indirme bitince soner.
#define FLASH_LED_PIN 4

// ---- UART2 LOOPBACK SELF-TEST -------------------------------------------
// "FIZIKSEL HAT YOK (0 byte)" gorduysen once ESP'nin kendi UART'inin saglam
// olup olmadigini KANITLA:
//   1) Mega'yi cikar (kablolari sok).
//   2) ESP GPIO15 (TX2) -> GPIO13 (RX2) arasina kisa bir jumper tak (DOGRUDAN,
//      gerilim bolucu YOK; ikisi de 3.3V).
//   3) Asagidaki 1 yapip yukle.
// Sonuc:
//   - byte/lines ARTIYORSA  -> ESP UART2 + GPIO13/15 SAGLAM. Sorun %100 Mega
//     kablolamasinda: ORTAK GND yok / gerilim bolucu / Mega TX1=pin18 degil.
//   - hala 0 byte           -> ESP pini/UART sorunlu; MEGA_RX_PIN'i degistir
//     (orn. 14) ya da baska bir ESP32 kullan.
// Test bitince tekrar 0 yapip Mega'yi geri bagla.
#define MEGA_SELFTEST 0

const char* AP_SSID = "Otoskop";
const char* AP_PASS = "otoskop123";   // en az 8 karakter

// mDNS adi: app cihazi "otoskop.local" olarak bulur (IP degisse de). Ayni ad
// ArduinoOTA hostname'i olarak da kullanilir.
const char* MDNS_HOST = "otoskop";
const char* OTA_PASS  = "otoskop123";   // kablosuz yukleme sifresi

// ----- Internet baglantisi (STA) -> hem internet ihtiyaci hem bulut OTA -----
// Birden fazla ag tanimla; ESP hangisi varsa ona baglanir (WiFiMulti).
// Yeni ag eklemek icin satir ekle, gerekmeyeni sil.
struct WifiCred { const char* ssid; const char* pass; };
WifiCred WIFI_NETS[] = {
  { "Nothing", "123456789a" },
};
WiFiMulti wifiMulti;

// ----- Bulut OTA (HTTP pull) ------------------------------------------------
// Her yeni firmware'de bu sayiyi VE version.json icindeki "version"i artir.
#define FW_VERSION 16

// version.json'in ham (raw) adresi. Ornek GitHub raw:
//   https://raw.githubusercontent.com/KULLANICI/REPO/main/ota/version.json
const char* OTA_VERSION_URL = "https://raw.githubusercontent.com/mraposka/Otoskop-Bitirme/refs/heads/main/Firmware/ESP32_Pure_Firmware/ota/version.json";

// Bulut OTA kontrol araligi (ms). 0 = otomatik kontrol kapali (sadece /ota/check).
const unsigned long OTA_CHECK_INTERVAL = 5UL * 60UL * 1000UL;  // 5 dk
unsigned long lastOtaCheck = 0;

WebServer server(80);          // API (status/komut/snapshot) - hizli cevap verir
// MJPEG stream'i AYRI bir port'ta (81) servis ediyoruz. Tek-is parcacikli
// WebServer, /stream'in sonsuz dongusunde TIKANIR; ayni port'taki /status ve
// komutlar cevapsiz kalir ("ESP32 baglantisi saglanmadi"). Stream'i ayri
// server'a alip, stream dongusunun icinde API server'ini de pompalayarak
// (server.handleClient) yayim sirasinda da API'yi canli tutuyoruz.
WebServer streamServer(81);    // sadece /stream (MJPEG)
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

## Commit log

2026-06-10 chore: combined repos
    [360 altın üstü plaka (Montaj).stl, 360 üst parça.stl, Alt_Parca.stl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]
2026-06-12 fix: astronomy api and scan algorithm
    [DemoEsp32Repository.kt]
